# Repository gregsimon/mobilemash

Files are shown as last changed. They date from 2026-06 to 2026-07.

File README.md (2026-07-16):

# MobileMash - ESP32 Phone Button Presser

A 3D-printable, ESP32-controlled servo harness for programmatically pressing
phone buttons. Primary use case: booting phones into fastboot mode unattended.

## Supported Phones

| Phone | Status |
|---|---|
| Pixel 10 Pro | v1 |

## How It Works

Two SG90 micro servos are mounted in a 3D-printed cradle that clips around the
phone. Each servo has a small arm that presses a button (power, volume-down).
An ESP32 dev board drives the servos and accepts commands over USB serial.

### Fastboot Sequence

1. **Force shutdown** - Press and hold power for up to 30 seconds (or until
   told to release).
2. **Enter fastboot** - Hold volume-down, then briefly press power. Release
   when told or after a safety timeout.

## Hardware BOM

| Part | Qty | Notes |
|---|-----|---|
| ESP32 DevKit v1 (or similar) | 1 | Any ESP32 board with USB |
| SG90 micro servo | 2 | 9g, 180-degree |
| M2x8 self-tapping screws | 4 | Mount servos to cradle |
| Rubber/silicone bumper pads | 2 | Glue to servo arms for grip |
| USB-A to micro-USB cable | 1 | Power + data to ESP32 |
| 470uF electrolytic capacitor | 1 | Optional, across servo 5V/GND |

## Wiring

Servo signal pins depend on the board (see `firmware/include/config.h`):

| Signal | ESP32 DevKit | XIAO ESP32-C6 |
|---|---|---|
| Power servo (orange) | GPIO 13 | GPIO 18 (D10) |
| Volume-up servo (orange) | — | GPIO 20 (D9)  |
| Volume-down servo (orange) | GPIO 14 | GPIO 19 (D8)  |
| OLED SDA | — | GPIO 2 (D2) |
| OLED SCL | — | GPIO 21 (D3)  |

The volume-up servo exists only on the XIAO ESP32-C6 build (commands
`PRESS_VOLUP` / `ANGLE_VOLUP`); the DevKit build has power + volume-down only.

The XIAO ESP32-C6 build also drives a 128x64 SSD1306 OLED over I2C
(address `0x3C`), which shows `Fuchsia` on boot. The DevKit build has no
display.

```
<board> 5V/5V-out --> Both servo VCC (red)
<board> GND       --> Both servo GND (brown)
```

## Firmware

Built with PlatformIO (Arduino framework). Two build environments are
defined in `firmware/platformio.ini`:

- `esp32` — ESP32 DevKit (default)
- `seeed` — Seeed XIAO ESP32-C6

```bash
cd firmware

# ESP32 DevKit (default env)
pio run -e esp32 -t upload

# Seeed XIAO ESP32-C6
pio run -e seeed -t upload

# Or via the helper script:
./flash.sh                     # DevKit
./flash.sh seeed  # XIAO ESP32-C6
```

### Serial Protocol (115200 baud)

Commands are newline-terminated ASCII:

| Command | Description |
|---|---|
| `PRESS_POWER <ms>` | Press power button for `<ms>` milliseconds |
| `PRESS_VOLDN <ms>` | Press volume-down for `<ms>` milliseconds |
| `FASTBOOT [shutdown_ms] [combo_ms]` | Run full fastboot entry sequence |
| `RELEASE_ALL` | Immediately release all buttons |
| `STATUS` | Report current state |
| `PING` | Returns `PONG` |

Responses are newline-terminated:

| Response | Meaning |
|---|---|
| `OK <detail>` | Command accepted / completed |
| `ERR <detail>` | Error |
| `STATE <json>` | Status response |
| `PONG` | Ping reply |

## 3D Printing

OpenSCAD source in `cad/`. Export STL and print with:
- Material: PLA or PETG
- Layer height: 0.2mm
- Infill: 20%+
- Supports: not required

## Host Tool

```bash
pip install pyserial
python host/mobilemash_cli.py --port /dev/ttyUSB0 fastboot
```

## License

Apache 2.0

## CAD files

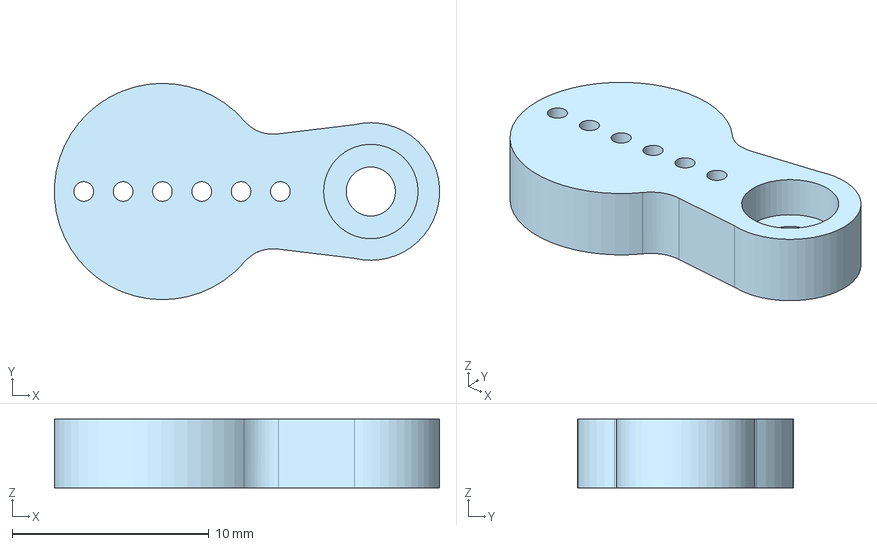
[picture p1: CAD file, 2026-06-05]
cad/sg90-masher-horn.step
19.6 x 11.0 x 3.50 mm

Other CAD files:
cad/sg90-masher-horn.stl

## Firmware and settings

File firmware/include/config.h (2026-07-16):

#pragma once

// ---------- Servo GPIO pins ----------
// Pins differ per board; the active board is selected by a -D flag in
// platformio.ini (BOARD_ESP32_DEVKIT or BOARD_XIAO_ESP32C6).
// A board that defines PIN_SERVO_VOLUP gets a third (volume-up) servo;
// boards that leave it undefined build without one.
#if defined(BOARD_XIAO_ESP32C6)
  // Seeed XIAO ESP32-C6
  #define PIN_SERVO_POWER   18   // D10
  #define PIN_SERVO_VOLUP   20   // D9
  #define PIN_SERVO_VOLDN   19   // D8
  // SSD1306 128x64 OLED on I2C
  #define HAS_OLED
  #define PIN_I2C_SDA       2    // D2
  #define PIN_I2C_SCL       21   // D3
  #define OLED_WIDTH        128
  #define OLED_HEIGHT       64
  #define OLED_I2C_ADDR     0x3C
  #define OLED_ROTATION     2    // 0=none, 1=90°, 2=180°, 3=270°
  // Rotary encoder with push-button switch. Drives an on-device menu shown on
  // the OLED: turning scrolls the selection, pressing runs it.
  #define HAS_ENCODER
  #define PIN_ENC_A         17   // D7  (header pin 14) quadrature channel A
  #define PIN_ENC_B         22   // D4  (header pin 5)  quadrature channel B
  #define PIN_ENC_SW        23   // D5  (header pin 6)  push-button (active low)
  // Momentary panic button — releases every servo back to its home position
  // from anywhere (active low, internal pull-up).
  #define PIN_PANIC         16   // D6  (header pin 7)
#elif defined(BOARD_ESP32_DEVKIT)
  // ESP32 DevKit (power + volume-down only)
  #define PIN_SERVO_POWER   13
  #define PIN_SERVO_VOLDN   14
#else
  #error "No board selected — define BOARD_ESP32_DEVKIT or BOARD_XIAO_ESP32C6 (see platformio.ini)"
#endif

// ---------- Servo angles (degrees) ----------
// "Released" = arm is away from the button.
// "Pressed"  = arm pushes the button.
// Tune these per-build until the arm cleanly presses the button.
#define ANGLE_POWER_RELEASED  0
#define ANGLE_POWER_PRESSED   75

#define ANGLE_VOLDN_RELEASED  0
#define ANGLE_VOLDN_PRESSED   55

#ifdef PIN_SERVO_VOLUP
#define ANGLE_VOLUP_RELEASED  0
#define ANGLE_VOLUP_PRESSED   55
#endif

// ---------- Timing defaults (ms) ----------
#define DEFAULT_SHUTDOWN_HOLD_MS   45000   // 45 s power hold for force-off
#define DEFAULT_FASTBOOT_COMBO_MS   5000   // 5 s vol-down + power tap
#define POWER_TAP_MS                1000   // brief power press in combo
#define SAFETY_TIMEOUT_MS          60000   // hard cap on any single hold

// ---------- Serial ----------
#define SERIAL_BAUD  115200

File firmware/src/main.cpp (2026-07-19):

/*
 * MobileMash – ESP32 phone-button presser firmware
 *
 * Drives two SG90 servos (power button, volume-down button) via simple
 * ASCII commands over USB serial.  Primary use case: programmatic fastboot
 * entry for Pixel phones.
 *
 * SPDX-License-Identifier: Apache-2.0
 */

#include <Arduino.h>
#include <ESP32Servo.h>
#include <Preferences.h>
#include "config.h"
#ifdef HAS_OLED
#include <Wire.h>
#include <Adafruit_SSD1306.h>
#endif

static volatile uint32_t lastSerialTrafficMs = 0;

// ── Servos ──────────────────────────────────────────────────────────────
Servo servoPower;
Servo servoVolDn;
#ifdef PIN_SERVO_VOLUP
Servo servoVolUp;
#endif
static Preferences preferences;
#ifdef HAS_OLED
static Adafruit_SSD1306 oled(OLED_WIDTH, OLED_HEIGHT, &Wire, -1);

// Probe the I2C bus and report every device that ACKs. Handy for confirming
// the display is wired correctly and which address it answers on (0x3C vs
// 0x3D are both common for SSD1306-class modules).
static void i2cScan() {
    Serial.println("I2C scan:");
    uint8_t found = 0;
    for (uint8_t addr = 1; addr < 127; addr++) {
        Wire.beginTransmission(addr);
        if (Wire.endTransmission() == 0) {
            Serial.printf("  device at 0x%02X\n", addr);
            found++;
        }
    }
    if (found == 0) Serial.println("  (none — check wiring/power)");
}

// Show a single line of text (large font) on the OLED.
static void oledShow(const char *msg) {
    oled.clearDisplay();
    oled.setTextSize(2);
    oled.setTextColor(SSD1306_WHITE);
    int len = strlen(msg);
    int x = (OLED_WIDTH - len * 12) / 2;
    if (x < 0) x = 0;
    oled.setCursor(x, 24);
    oled.println(msg);
    oled.display();
}

static void drawFooter(const char *text) {
    oled.drawFastHLine(0, 47, OLED_WIDTH, SSD1306_WHITE);
    int len = strlen(text);
    int x = (OLED_WIDTH - (len * 6)) / 2;
    if (x < 0) x = 0;
    oled.setCursor(x, 52);
    oled.print(text);

    // Draw Serial port connection & traffic indicator on the far right
    bool isConnected = (bool)Serial;
    bool hasTraffic = (millis() - lastSerialTrafficMs < 150);
    oled.setCursor(98, 52);
    if (hasTraffic) {
        oled.print("<-*->");
    } else if (isConnected) {
        oled.print(" <-->");
    } else {
        oled.print("     ");
    }
}
#endif

static bool powerPressed = false;
static bool volDnPressed = false;
#ifdef PIN_SERVO_VOLUP
static bool volUpPressed = false;
#endif

// ── Tunable servo angles ────────────────────────────────────────────────
// Seeded from the config.h defaults but adjustable at runtime via the
// on-device "Tuning" menu (see below). "Released"/start = arm away from the
// button, "Pressed"/stop = arm pushing it.
static int anglePowerReleased = ANGLE_POWER_RELEASED;
static int anglePowerPressed  = ANGLE_POWER_PRESSED;
static int angleVoldnReleased = ANGLE_VOLDN_RELEASED;
static int angleVoldnPressed  = ANGLE_VOLDN_PRESSED;
#ifdef PIN_SERVO_VOLUP
static int angleVolupReleased = ANGLE_VOLUP_RELEASED;
static int angleVolupPressed  = ANGLE_VOLUP_PRESSED;
#endif

// ── Helpers ─────────────────────────────────────────────────────────────

static void pressPower() {
    servoPower.write(anglePowerPressed);
    powerPressed = true;
}
static void releasePower() {
    servoPower.write(anglePowerReleased);
    powerPressed = false;
}
static void pressVolDn() {
    servoVolDn.write(angleVoldnPressed);
    volDnPressed = true;
}
static void releaseVolDn() {
    servoVolDn.write(angleVoldnReleased);
    volDnPressed = false;
}
#ifdef PIN_SERVO_VOLUP
static void pressVolUp() {
    servoVolUp.write(angleVolupPressed);
    volUpPressed = true;
}
static void releaseVolUp() {
    servoVolUp.write(angleVolupReleased);
    volUpPressed = false;
}
#endif
static void releaseAll() {
    releasePower();
    releaseVolDn();
#ifdef PIN_SERVO_VOLUP
    releaseVolUp();
#endif
}

// Block while holding, but keep reading serial for an early-release command.
// Returns true if we were interrupted by RELEASE_ALL, false if the duration
// expired normally.
static bool holdWithInterrupt(unsigned long durationMs) {
    unsigned long start = millis();
    while (millis() - start < durationMs) {
        if (Serial.available()) {
            lastSerialTrafficMs = millis();
            String line = Serial.readStringUntil('\n');
            line.trim();
            if (line == "RELEASE_ALL") {
                releaseAll();
                Serial.println("OK RELEASE_ALL (interrupted hold)");
                return true;
            }
        }
        delay(10);
    }
    return false;
}

// ── Command handlers ────────────────────────────────────────────────────

static void cmdPressButton(void (*press)(), void (*release)(),
                           const char *name, unsigned long ms) {
    if (ms == 0 || ms > SAFETY_TIMEOUT_MS) {
        Serial.printf("ERR duration out of range (1-%lu)\n", SAFETY_TIMEOUT_MS);
        return;
    }
    Serial.printf("OK pressing %s for %lu ms\n", name, ms);
    press();
    bool interrupted = holdWithInterrupt(ms);
    if (!interrupted) {
        release();
        Serial.printf("OK released %s\n", name);
    }
}

static void cmdFastboot(unsigned long shutdownMs, unsigned long comboMs) {
    if (shutdownMs > SAFETY_TIMEOUT_MS) shutdownMs = SAFETY_TIMEOUT_MS;
    if (comboMs > SAFETY_TIMEOUT_MS)    comboMs    = SAFETY_TIMEOUT_MS;

    // Phase 1: force-shutdown by holding power
    Serial.printf("OK FASTBOOT phase1: holding power %lu ms\n", shutdownMs);
    pressPower();
    bool interrupted = holdWithInterrupt(shutdownMs);
    if (interrupted) return;
    releasePower();
    Serial.println("OK FASTBOOT phase1 done (power released)");

    // Brief pause to let the phone fully shut down
    delay(1000);

    // Phase 2: hold volume-down, then tap power
    // Stagger servo movements and detach vol-down PWM before moving power
    // to avoid brownout from simultaneous current draw.  The vol-down servo
    // holds its position via gear friction while unpowered.
    Serial.printf("OK FASTBOOT phase2: vol-down + power tap (%lu ms window)\n",
                  comboMs);
    pressVolDn();
    delay(500);            // hold vol-down for 500ms before moving power
    servoVolDn.detach();   // stop PWM — servo holds via friction
    delay(100);
    pressPower();

    unsigned long tapStart = millis();

    // Keep power pressed for POWER_TAP_MS or until interrupted
    while (millis() - tapStart < POWER_TAP_MS) {
        if (Serial.available()) {
            lastSerialTrafficMs = millis();
            String line = Serial.readStringUntil('\n');
            line.trim();
            if (line == "RELEASE_ALL") {
                servoVolDn.attach(PIN_SERVO_VOLDN, 500, 2400);
                releaseAll();
                Serial.println("OK RELEASE_ALL (fastboot interrupted)");
                return;
            }
        }
        delay(10);
    }
    releasePower();  // release power after tap
    Serial.println("OK FASTBOOT power released, holding vol-down 5000 ms");

    // Re-attach vol-down and keep holding it for 5000ms after power release
    servoVolDn.attach(PIN_SERVO_VOLDN, 500, 2400);
    pressVolDn();  // re-assert vol-down now that power servo is idle

    bool postHoldInterrupted = holdWithInterrupt(5000);

    if (!postHoldInterrupted) {
        releaseAll();
        Serial.println("OK FASTBOOT complete");
    }
}

static void cmdStatus() {
#ifdef PIN_SERVO_VOLUP
    Serial.printf("STATE {\"power\":%s,\"volup\":%s,\"voldn\":%s}\n",
                  powerPressed ? "true" : "false",
                  volUpPressed ? "true" : "false",
                  volDnPressed ? "true" : "false");
#else
    Serial.printf("STATE {\"power\":%s,\"voldn\":%s}\n",
                  powerPressed ? "true" : "false",
                  volDnPressed ? "true" : "false");
#endif
}

// ── Rotary encoder + on-device menu ─────────────────────────────────────
#ifdef HAS_ENCODER
// Half-step quadrature decoder (Ben Buxton state table). Each ISR reads both
// channels and advances a state machine; contact bounce is absorbed as no-ops.
// This EC11 rests a detent at every HALF electrical cycle, so the half-step
// table (which emits at both the 00 and 11 rest points) yields one step per
// detent — 1:1 with the menu. A full-step table would need two detents per step.
#define R_START       0x0
#define R_CCW_BEGIN   0x1
#define R_CW_BEGIN    0x2
#define R_START_M     0x3
#define R_CW_BEGIN_M  0x4
#define R_CCW_BEGIN_M 0x5
#define DIR_CW        0x10
#define DIR_CCW       0x20

static const uint8_t ENC_TABLE[6][4] = {
    {R_START_M,           R_CW_BEGIN,    R_CCW_BEGIN,   R_START},
    {R_START_M | DIR_CCW, R_START,       R_CCW_BEGIN,   R_START},
    {R_START_M | DIR_CW,  R_CW_BEGIN,    R_START,       R_START},
    {R_START_M,           R_CCW_BEGIN_M, R_CW_BEGIN_M,  R_START},
    {R_START_M,           R_START_M,     R_CW_BEGIN_M,  R_START | DIR_CW},
    {R_START_M,           R_CCW_BEGIN_M, R_START_M,     R_START | DIR_CCW},
};

static volatile uint8_t  encState    = R_START;
static volatile int8_t   encoderDelta = 0;   // detent steps, consumed in loop()
static volatile uint32_t encIsrCount = 0;    // A/B edges seen (diagnostic)

static void IRAM_ATTR encoderISR() {
    encIsrCount++;
    uint8_t pins = (digitalRead(PIN_ENC_A) << 1) | digitalRead(PIN_ENC_B);
    encState = ENC_TABLE[encState & 0x0f][pins];
    uint8_t dir = encState & 0x30;
    if (dir == DIR_CW)       encoderDelta++;
    else if (dir == DIR_CCW) encoderDelta--;
}

// Report raw encoder state — helps localize a fault: rotate slowly and watch
// whether the edge count climbs and A/B toggle, and whether SW drops to 0 when
// the knob is pressed.
static void cmdEncDebug() {
    Serial.printf("ENC A=%d B=%d SW=%d edges=%lu delta=%d\n",
                  digitalRead(PIN_ENC_A), digitalRead(PIN_ENC_B),
                  digitalRead(PIN_ENC_SW), (unsigned long)encIsrCount,
                  encoderDelta);
}

// Read every free XIAO header pin (servos use D8/D9/D10, I2C uses D2/D3) with
// internal pull-ups engaged. Turn the knob and watch which two toggle — those
// are the true A/B GPIOs; press it and watch which drops — that is SW.
struct ScanPin { const char *label; uint8_t gpio; };
static const ScanPin SCAN_PINS[] = {
    {"D0",  0}, {"D1", 1}, {"D6", 16}, {"D7", 17}, {"D4", 22}, {"D5", 23},
};
static const int SCAN_COUNT = sizeof(SCAN_PINS) / sizeof(SCAN_PINS[0]);

static void cmdScan() {
    Serial.print("SCAN");
    for (int i = 0; i < SCAN_COUNT; i++) {
        pinMode(SCAN_PINS[i].gpio, INPUT_PULLUP);
        Serial.printf(" %s(g%u)=%d", SCAN_PINS[i].label, SCAN_PINS[i].gpio,
                      digitalRead(SCAN_PINS[i].gpio));
    }
    Serial.println();
}

// Menu actions. Taps reuse the servo helpers; a tap keeps serial responsive so
// RELEASE_ALL still interrupts it.
static void actPowerTap()  { pressPower();  holdWithInterrupt(POWER_TAP_MS); releasePower();  }
#ifdef PIN_SERVO_VOLUP
static void actVolUp()     { pressVolUp();  holdWithInterrupt(300);          releaseVolUp();  }
#endif
static void actVolDn()     { pressVolDn();  holdWithInterrupt(300);          releaseVolDn();  }
static void actFastboot()  { cmdFastboot(DEFAULT_SHUTDOWN_HOLD_MS, DEFAULT_FASTBOOT_COMBO_MS); }

// A main-menu entry runs an action; the special "Tuning" entry (run == nullptr)
// opens the tuning submenu instead of running a blocking action.
struct MenuItem { const char *name; void (*run)(); };
static const MenuItem MENU[] = {
    {"Power tap", actPowerTap},
#ifdef PIN_SERVO_VOLUP
    {"Vol Up",    actVolUp},
#endif
    {"Vol Down",  actVolDn},
    {"Fastboot",  actFastboot},
    {"Tuning",    nullptr},
};
static const int MENU_COUNT = sizeof(MENU) / sizeof(MENU[0]);

// Each servo's tunable start/stop angles, indexed by the tuning submenu.
struct ServoTune {
    const char *name;
    Servo      *servo;
    int        *start;   // released angle (arm away)
    int        *stop;    // pressed angle  (arm on the button)
};
static ServoTune SERVOS[] = {
    {"Power",    &servoPower, &anglePowerReleased, &anglePowerPressed},
#ifdef PIN_SERVO_VOLUP
    {"Vol Up",   &servoVolUp, &angleVolupReleased, &angleVolupPressed},
#endif
    {"Vol Down", &servoVolDn, &angleVoldnReleased, &angleVoldnPressed},
};
static const int SERVO_COUNT = sizeof(SERVOS) / sizeof(SERVOS[0]);

// Menu navigation state. The encoder drives a small stack of screens:
//   MAIN → SERVOS (pick a servo) → PARAMS (Start/Stop/Back) → EDIT (live angle)
enum MenuMode { MODE_MAIN, MODE_SERVOS, MODE_PARAMS, MODE_EDIT };
static MenuMode menuMode  = MODE_MAIN;
static int      menuIndex = 0;   // selection within the current screen
static int      tuneServo = 0;   // servo chosen in MODE_SERVOS
static int      tuneParam = 0;   // 0 = start, 1 = stop (chosen in MODE_PARAMS)
static int      editAngle = 0;   // working angle while in MODE_EDIT

// Number of selectable rows on the current screen (SERVOS/PARAMS include Back).
static int currentCount() {
    switch (menuMode) {
        case MODE_MAIN:   return MENU_COUNT;
        case MODE_SERVOS: return SERVO_COUNT + 1;   // servos + Back
        case MODE_PARAMS: return 3;                 // Start, Stop, Back
        default:          return 1;
    }
}

// Draw whichever screen is active, with a ">" cursor on the current selection.
#define MAX_VISIBLE_ITEMS 3
#define ITEM_SPACING 11
#define MENU_START_Y 13

static void drawMenu() {
    oled.clearDisplay();
    oled.setTextSize(1);
    oled.setTextColor(SSD1306_WHITE);
    oled.setCursor(0, 0);

    // Calculate scroll offset for scrollable menus (MODE_MAIN, MODE_SERVOS, MODE_PARAMS)
    int scrollOffset = 0;
    int totalItems = currentCount();
    if (menuMode == MODE_MAIN || menuMode == MODE_SERVOS || menuMode == MODE_PARAMS) {
        static int lastMenuMode = -1;
        static int prevScrollOffset = 0;
        if ((int)menuMode != lastMenuMode) {
            prevScrollOffset = 0;
            lastMenuMode = (int)menuMode;
        }
        
        if (menuIndex < prevScrollOffset) {
            prevScrollOffset = menuIndex;
        } else if (menuIndex >= prevScrollOffset + MAX_VISIBLE_ITEMS) {
            prevScrollOffset = menuIndex - MAX_VISIBLE_ITEMS + 1;
        }
        
        int maxScroll = totalItems - MAX_VISIBLE_ITEMS;
        if (maxScroll < 0) maxScroll = 0;
        if (prevScrollOffset > maxScroll) {
            prevScrollOffset = maxScroll;
        }
        if (prevScrollOffset < 0) {
            prevScrollOffset = 0;
        }
        scrollOffset = prevScrollOffset;
    }

    if (menuMode == MODE_MAIN) {
        oled.println("MobileMash");
        oled.drawFastHLine(0, 10, OLED_WIDTH, SSD1306_WHITE);
        for (int i = 0; i < MAX_VISIBLE_ITEMS; i++) {
            int idx = scrollOffset + i;
            if (idx >= MENU_COUNT) break;
            oled.setCursor(0, MENU_START_Y + i * ITEM_SPACING);
            oled.printf("%c %s", (idx == menuIndex) ? '>' : ' ', MENU[idx].name);
        }
        drawFooter("");
    } else if (menuMode == MODE_SERVOS) {
        oled.println("Tuning");
        oled.drawFastHLine(0, 10, OLED_WIDTH, SSD1306_WHITE);
        for (int i = 0; i < MAX_VISIBLE_ITEMS; i++) {
            int idx = scrollOffset + i;
            if (idx >= SERVO_COUNT + 1) break;
            oled.setCursor(0, MENU_START_Y + i * ITEM_SPACING);
            if (idx == SERVO_COUNT) {
                oled.printf("%c Back", (idx == menuIndex) ? '>' : ' ');
            } else {
                oled.printf("%c %s", (idx == menuIndex) ? '>' : ' ', SERVOS[idx].name);
            }
        }
        drawFooter("");
    } else if (menuMode == MODE_PARAMS) {
        oled.println(SERVOS[tuneServo].name);
        oled.drawFastHLine(0, 10, OLED_WIDTH, SSD1306_WHITE);
        for (int i = 0; i < MAX_VISIBLE_ITEMS; i++) {
            int idx = scrollOffset + i;
            if (idx >= 3) break;
            oled.setCursor(0, MENU_START_Y + i * ITEM_SPACING);
            if (idx == 0) {
                oled.printf("%c Start  %3d", (idx == menuIndex) ? '>' : ' ',
                            *SERVOS[tuneServo].start);
            } else if (idx == 1) {
                oled.printf("%c Stop   %3d", (idx == menuIndex) ? '>' : ' ',
                            *SERVOS[tuneServo].stop);
            } else {
                oled.printf("%c Back", (idx == menuIndex) ? '>' : ' ');
            }
        }
        drawFooter("");
    } else {  // MODE_EDIT
        oled.printf("%s %s\n", SERVOS[tuneServo].name,
                    (tuneParam == 0) ? "Start" : "Stop");
        oled.drawFastHLine(0, 10, OLED_WIDTH, SSD1306_WHITE);
        oled.setTextSize(3);
        int numDigits = (editAngle >= 100) ? 3 : ((editAngle >= 10) ? 2 : 1);
        int xPos = (OLED_WIDTH - (numDigits * 18 - 3)) / 2;
        oled.setCursor(xPos, 19);
        oled.printf("%d", editAngle);
        oled.setTextSize(1);
        drawFooter("adjust  save");
    }
    oled.display();
}

// Run a main-menu action, showing a "Running" screen while it blocks, then
// return to the menu.
static void runMenuItem(int idx) {
    oled.clearDisplay();
    oled.setTextSize(1);
    oled.setTextColor(SSD1306_WHITE);
    oled.setCursor(0, 0);
    oled.println("Running:");
    oled.drawFastHLine(0, 10, OLED_WIDTH, SSD1306_WHITE);
    
    int len = strlen(MENU[idx].name);
    int x = (OLED_WIDTH - len * 12) / 2;
    if (x < 0) x = 0;
    oled.setCursor(x, 22);
    oled.setTextSize(2);
    oled.println(MENU[idx].name);
    
    oled.setTextSize(1);
    drawFooter("running...");
    oled.display();
    Serial.printf("OK encoder run: %s\n", MENU[idx].name);
    MENU[idx].run();
    drawMenu();
}

// Handle a button press: activate the current selection for whichever screen
// is active, transitioning between screens as needed.
static void menuSelect() {
    switch (menuMode) {
    case MODE_MAIN:
        if (MENU[menuIndex].run == nullptr) {   // "Tuning" → open submenu
            menuMode  = MODE_SERVOS;
            menuIndex = 0;
            drawMenu();
        } else {
            runMenuItem(menuIndex);
        }
        break;

    case MODE_SERVOS:
        if (menuIndex == SERVO_COUNT) {         // Back → main menu
            menuMode  = MODE_MAIN;
            menuIndex = MENU_COUNT - 1;          // land back on "Tuning"
        } else {
            tuneServo = menuIndex;
            menuMode  = MODE_PARAMS;
            menuIndex = 0;
        }
        drawMenu();
        break;

    case MODE_PARAMS:
        if (menuIndex == 2) {                    // Back → servo list
            menuMode  = MODE_SERVOS;
            menuIndex = tuneServo;
        } else {                                 // edit Start or Stop live
            tuneParam = menuIndex;
            editAngle = (tuneParam == 0) ? *SERVOS[tuneServo].start
                                         : *SERVOS[tuneServo].stop;
            SERVOS[tuneServo].servo->write(editAngle);   // preview current
            menuMode  = MODE_EDIT;
        }
        drawMenu();
        break;

    case MODE_EDIT:                              // save and step back out
        if (tuneParam == 0) *SERVOS[tuneServo].start = editAngle;
        else                *SERVOS[tuneServo].stop  = editAngle;
        Serial.printf("OK tune %s %s=%d\n", SERVOS[tuneServo].name,
                      (tuneParam == 0) ? "start" : "stop", editAngle);

        // Save updated angle to non-volatile storage
        preferences.begin("servo_angles", false);
        if (tuneServo == 0) { // Power
            preferences.putInt(tuneParam == 0 ? "p_rel" : "p_prs", editAngle);
        }
#ifdef PIN_SERVO_VOLUP
        else if (tuneServo == 1) { // Vol Up
            preferences.putInt(tuneParam == 0 ? "vu_rel" : "vu_prs", editAngle);
        }
        else if (tuneServo == 2) { // Vol Down
            preferences.putInt(tuneParam == 0 ? "vd_rel" : "vd_prs", editAngle);
        }
#else
        else if (tuneServo == 1) { // Vol Down
            preferences.putInt(tuneParam == 0 ? "vd_rel" : "vd_prs", editAngle);
        }
#endif
        preferences.end();

        // Park the arm back at its start angle so it isn't left pressing.
        SERVOS[tuneServo].servo->write(*SERVOS[tuneServo].start);
        menuMode  = MODE_PARAMS;
        menuIndex = tuneParam;
        drawMenu();
        break;
    }
}
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
void loop() {
    if (Serial.available()) {
        lastSerialTrafficMs = millis();
        String line = Serial.readStringUntil('\n');
        processLine(line);
    }
#ifdef HAS_ENCODER
    handleEncoder();
#endif
#ifdef PIN_PANIC
    handlePanicButton();
#endif

    // Redraw screen if serial connection status or traffic status changes
    #ifdef HAS_OLED
      #ifdef HAS_ENCODER
        static bool wasSerialConnected = false;
        static bool wasTraffic = false;
        
        bool isSerialConnected = (bool)Serial;
        bool isTraffic = (millis() - lastSerialTrafficMs < 150);
        
        if (isSerialConnected != wasSerialConnected || isTraffic != wasTraffic) {
            wasSerialConnected = isSerialConnected;
            wasTraffic = isTraffic;
            drawMenu();
        }
      #endif
    #endif
}

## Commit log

2026-06-05 Add SG90 button-masher servo horn CAD files
    Custom SG90 servo horn optimized for pressing phone buttons, exported
    as STEP (AP242) and STL for printing.
    [sg90-masher-horn.step, sg90-masher-horn.stl]
2026-07-16 added support for seeed ESP32
2026-07-16 support for rotory encoder and menu
2026-07-16 support encoder
2026-07-16 add menu items for tuning servo positionsL
2026-07-16 make push button a panic button
2026-07-16 dislpay PANIC on screen when button is pushed
2026-07-19 save servo start/stop positions in ESP nonv memory
